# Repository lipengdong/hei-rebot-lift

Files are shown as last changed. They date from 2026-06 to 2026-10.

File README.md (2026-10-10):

<h1 align="center">HEI ReBot Lift</h1>

<p align="center">
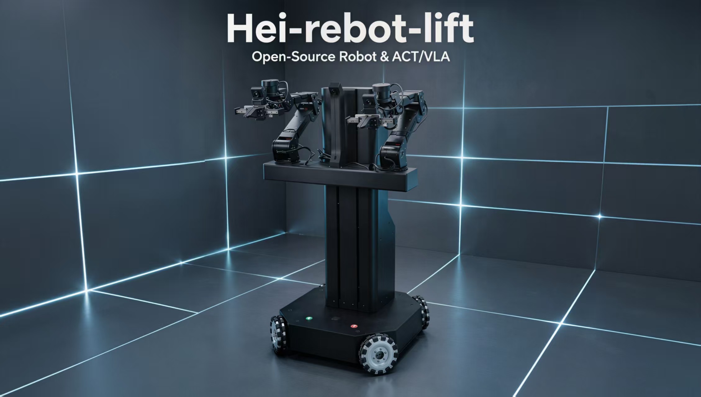
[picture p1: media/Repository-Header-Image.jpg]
HEI ReBot Lift
  
</p>

<p align="center">
  <a href="README.md"><b>English</b></a> <b>|</b>
  <a href="README_zh.md"><b>中文</b></a> <b>|</b>
  <a href="README_Fr.md"><b>français</b></a> <b>|</b>
  <a href="README_es.md"><b>Español</b></a>
</p>

<p align="center">
  <a href="https://github.com/lipengdong/hei-rebot-lift/tree/v0.2.0">
    
  </a>
  <a href="https://github.com/lipengdong/hei-rebot-lift/stargazers">
    
  </a>
</p>

## 🚀 Overview

**HEI ReBot Lift** is a **dual-arm lifting mobile robot project for embodied AI learning, reproduction, and real-robot validation**. Its goal is to **lower the barrier to building real robot learning systems**. It follows the idea of **truly reproducible open source**: not only releasing code, but also organizing **hardware materials, wiring, deployment steps, the VR teleoperation pipeline, dataset recording, ACT/VLA training, and real-robot rollout workflows**, so builders can move from hardware assembly all the way to policy deployment. The robot consists of dual arms, a lift platform, a four-wheel O-type omnidirectional chassis, and three cameras. The software is built on LeRobot and covers MuJoCo/Pinocchio inverse kinematics, LeRobotDataset, imitation learning, and VLA policy deployment.

<p align="center">
  <b>🚀 Dual-Arm Mobile Manipulation</b> · <b>📖 Open Hardware + Software Stack</b> · <b>🤖 LeRobot Ready</b>
</p>

<p align="center">
  <a href="#-quick-setup">🚀 Quick Setup</a> ·
  <a href="#-hardware">🦾 Hardware</a> ·
  <a href="#-startup-flow">🎮 Simulation / Teleoperation</a> ·
  <a href="#-record-data">📷 Record Data</a> ·
  <a href="#-train-act">🧠 Train ACT</a> ·
  <a href="#-train-smolvla">✨ Train VLA</a>
</p>

## ✨ Features

<div align="center">

<table>
  <thead>
    <tr>
      <th align="center">Icon</th>
      <th align="center">Capability</th>
      <th align="center">Description</th>
    </tr>
  </thead>
  <tbody>
    <tr><td align="center">🦾</td><td align="center">Dual-arm manipulation</td><td align="center">Damiao dual arms and grippers for teleoperation, recording, and policy rollout</td></tr>
    <tr><td align="center">⬆️</td><td align="center">Lift platform</td><td align="center">Automatic homing on startup, with the upper limit defined as <code>height.pos = 0</code></td></tr>
    <tr><td align="center">⭕</td><td align="center">Omnidirectional base</td><td align="center">Four-wheel O-type omnidirectional chassis with <code>x/y/theta</code> velocity control</td></tr>
    <tr><td align="center">🎮</td><td align="center">Keyboard / VR control</td><td align="center">Control the complete MuJoCo robot by keyboard or VR; Telegrip + Pinocchio/CasADi provide the VR IK pipeline</td></tr>
    <tr><td align="center">📷</td><td align="center">Three-camera data</td><td align="center"><code>front</code>, <code>left_wrist</code>, and <code>right_wrist</code> visual inputs</td></tr>
    <tr><td align="center">🧠</td><td align="center">Imitation learning / VLA</td><td align="center">Record keyboard/VR simulation data, visualize LeRobotDataset episodes, train ACT/VLA policies, and run them in simulation or on hardware</td></tr>
  </tbody>
</table>

HEI ReBot Lift demo

</div>

## 🤝 Get Your Own Robot / Join the Community

If you want to reproduce your own **HEI ReBot Lift**, you can follow the hardware materials, BOM, wiring notes, and software deployment documents gradually organized in this project to source parts and build the robot yourself. We also welcome builders and researchers interested in dual-arm mobile manipulation, VR teleoperation, LeRobot data collection, ACT/VLA training, and real-robot deployment to exchange ideas with us.

If you want to **get your own robot faster**, or would like to collaborate on hardware reproduction, teaching labs, data collection, algorithm validation, or application deployment, feel free to contact us.

<p align="center">
  <b>WeChat community / collaboration:</b> <code>hgm159951</code> &nbsp;&nbsp;|&nbsp;&nbsp;
  <b>Email:</b> <a href="mailto:hgm159951@163.com">hgm159951@163.com</a>
</p>

Reproductions, discussions, issues, improvements, and real-robot test feedback are all welcome.

## 📁 Project Layout

```text
hei-rebot-lift/
├── README.md
├── README_zh.md
├── README_Fr.md
├── README_es.md
├── LICENSE
├── community/                    # Community notes and collaboration records
├── hardware/                     # Hardware BOM, wiring, device binding, mechanical materials
├── media/                        # Images, videos, and README assets
├── docs/                         # Deployment and usage documentation
└── software/
    └── lerobot-hei-rebot-lift/   # Runnable LeRobot-based software project
```

The runnable software lives in:

```text
software/lerobot-hei-rebot-lift/
```

Quick Setup starts at the repository root. For later sections, open a new
terminal at the repository root for each command block; each block includes its
own `cd`. Replace `192.168.31.127` with your robot IP. The headset connects to
the **computer IP**, not the robot IP. The software directory is:

```bash
cd software/lerobot-hei-rebot-lift
```

## 🖼️ Showcase

<p align="center">
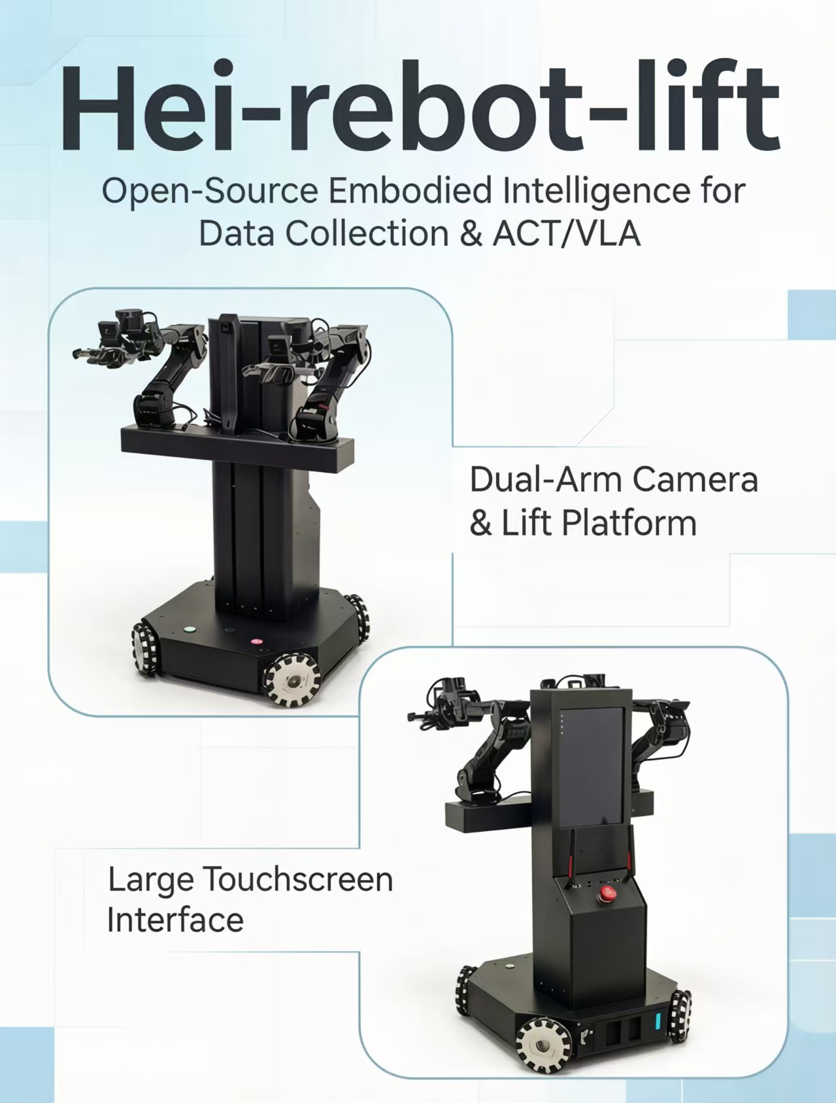
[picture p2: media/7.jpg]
HEI ReBot Lift robot
  
</p>

## ⭐ Star History

<p align="center">
  <a href="https://www.star-history.com/?repos=lipengdong%2Fhei-rebot-lift&type=date&legend=top-left">
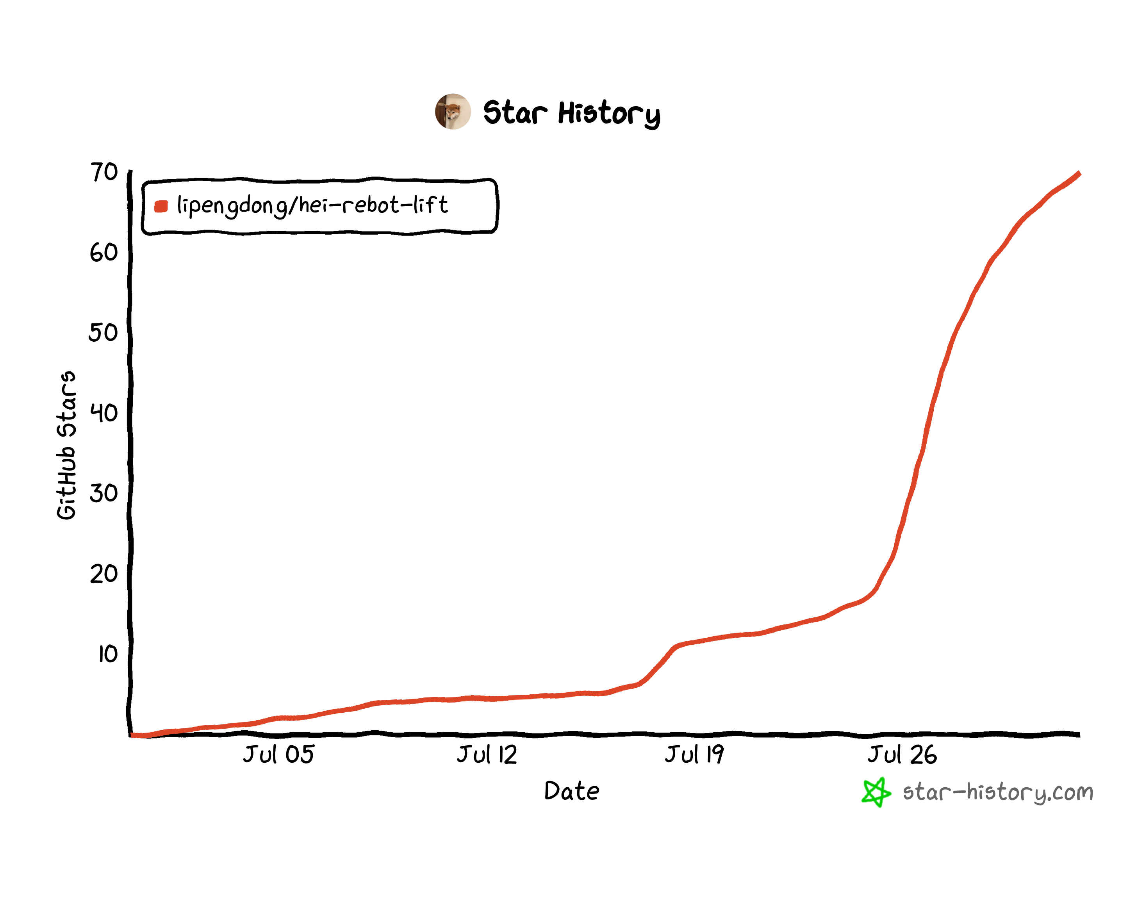
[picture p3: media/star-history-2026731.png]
HEI ReBot Lift Star History
    
  </a>
</p>

## 🗺️ Roadmap & Latest Status

We will continue improving HEI ReBot Lift across hardware materials, software interfaces, data collection workflows, and mainstream embodied AI policy integrations. The table below summarizes the current status and links to the related documentation.

| Module | Status | Current Progress | Related DOC |
| --- | --- | --- | --- |
| Robot body | ✅ First version completed | Dual arms, lift platform, and four-wheel O-type omnidirectional base are integrated and tested as a complete system | [Hardware](hardware/README.md) |
| Complete robot URDF | ✅ Completed | Full robot model includes the chassis, wheels, lift, dual arms, parallel grippers, and TCP frames for simulation and real-robot IK | [URDF Model](software/lerobot-hei-rebot-lift/examples/hei_rebot_lift/VR_mujoco_ik/mujoco_ik/model/HEI_robot_urdf/) |
| MuJoCo simulation testing | ✅ Completed | Keyboard and VR control of both arms, grippers, lift, and chassis have been tested; includes wheel animations, workspace projection, stable demonstrations, and independent contact-physics grasp validation | [Simulation Guide](software/lerobot-hei-rebot-lift/examples/hei_rebot_lift/VR_mujoco_ik/README.md) |
| Simulation data and policy loop | ✅ Verified | Keyboard or VR demonstrations publish synchronized 18-D states/actions and three camera views for LeRobotDataset recording, visualization, ACT training, and MuJoCo policy rollout | [Dataset, Training & Inference Guide](software/lerobot-hei-rebot-lift/examples/hei_rebot_lift/VR_mujoco_ik/mujoco_ik/SIM_DATASET_WORKFLOW.md) |
| Damiao motor driver | ✅ First version completed | `damiao_u2can` is implemented for dual arms, grippers, chassis, and lift motor control | [Damiao U2CAN](software/lerobot-hei-rebot-lift/src/lerobot/motors/damiao_u2can/) |
| Lift platform | ✅ First version completed | Supports upper-limit homing on startup and `height.pos` position-target control | [Robot Driver](software/lerobot-hei-rebot-lift/src/lerobot/robots/hei_rebot_lift/README.md) · [Independent Lift Control](software/lerobot-hei-rebot-lift/examples/hei_rebot_lift/README.md#independent-lift-test) |
| Omnidirectional base | ✅ First version completed | Supports `x.vel`, `y.vel`, and `theta.vel` commands with basic acceleration smoothing | [Robot Driver](software/lerobot-hei-rebot-lift/src/lerobot/robots/hei_rebot_lift/README.md) · [Independent Chassis Control](software/lerobot-hei-rebot-lift/examples/hei_rebot_lift/README.md#independent-chassis-test) |
| Three-camera vision | ✅ First version completed | Supports `front`, `left_wrist`, and `right_wrist` OpenCV cameras with MJPG by default | [Robot Driver](software/lerobot-hei-rebot-lift/src/lerobot/robots/hei_rebot_lift/README.md) |
| VR + MuJoCo IK | ✅ First version completed | Telegrip + MuJoCo + Pinocchio/CasADi is connected to the real-robot control pipeline | [VR MuJoCo IK](software/lerobot-hei-rebot-lift/examples/hei_rebot_lift/VR_mujoco_ik/README.md) |
| LeRobot 0.6.2 integration | ✅ Updated | `hei_rebot_lift` robot/client/host is adapted to the latest upstream interfaces, with teleoperate, record, replay, evaluate, and rollout scripts | [Examples](software/lerobot-hei-rebot-lift/examples/hei_rebot_lift/README.md) |
| Real-robot data collection | ✅ First version completed | Supports LeRobotDataset recording, resume recording, visualization, and bad-episode cleanup | [Record Guide](software/lerobot-hei-rebot-lift/examples/hei_rebot_lift/README.md) |
| ACT training and rollout | ✅ Verified | Supports ACT training and real-robot rollout | [Examples](software/lerobot-hei-rebot-lift/examples/hei_rebot_lift/README.md) |
| SmolVLA / VLA | ✅ Initial support | Supports SmolVLA training and real-robot rollout entry points | [Examples](software/lerobot-hei-rebot-lift/examples/hei_rebot_lift/README.md) |
| Open hardware materials | ✅ Completed | Overall BOM, full robot STEP assembly, printed-part STL files, metal parts list, and STEP/DWG manufacturing files are available | [Hardware](hardware/README.md) |
| Community and reproduction | 🚧 Ongoing | WeChat group, email contact, and GitHub project entry are available | [Community](community/README.md) |
| Other mainstream VLA deployment reproduction | ⏳ Coming soon | Plan to reproduce and test more mainstream VLA policies for training, inference, and real-robot deployment on HEI ReBot Lift | Not completed |

## 🦾 Hardware

The hardware package now includes the overall BOM, full robot STEP assembly, 3D printed parts, and metal/CNC/sheet-metal manufacturing files.

| Resource | File / Directory | Description |
| --- | --- | --- |
| Hardware guide | [hardware/README.md](hardware/README.md) | Hardware directory index, reproduction order, and safety checklist |
| Overall BOM V1.1 | [hardware/HEI_ReBot_Lift_BOM.md](hardware/HEI_ReBot_Lift_BOM.md) / [xlsx](hardware/HEI_ReBot_Lift_BOM.xlsx) | Main purchasing and preparation checklist; verify current prices before purchase |
| Full robot assembly | [hardware/Hei_robot_lift.STEP](hardware/Hei_robot_lift.STEP) | Full STEP model for structure review and assembly reference |
| 3D printed parts | [hardware/3D_Printed_Parts/](hardware/3D_Printed_Parts/) | STL files for printed covers, brackets, lift, chassis, and camera-related parts |
| Metal body parts list | [hardware/Metal_Parts/HEI_Metal_Body_Parts_List.xlsx](hardware/Metal_Parts/HEI_Metal_Body_Parts_List.xlsx) | Metal/CNC/sheet-metal part list |
| Metal CAD files | [hardware/Metal_Parts/step/](hardware/Metal_Parts/step/) / [hardware/Metal_Parts/dwg/](hardware/Metal_Parts/dwg/) | STEP and DWG files for machining communication |

### Assembly and Debugging Tutorial

Scan the QR code for the HEI ReBot Lift assembly and debugging tutorial. Use it
together with the repository BOM, latest CAD files, and safety checklist.

<p align="center">
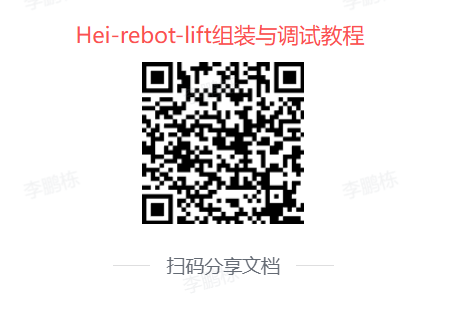
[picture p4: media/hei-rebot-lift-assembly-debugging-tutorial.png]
HEI ReBot Lift assembly and debugging tutorial QR code
  
  <br>
  <em>Scan to open the assembly and debugging tutorial.</em>
</p>

```text
Dual arms: left and right arms with 7 Damiao motors each. Joints 1-3 use DM4340P, joints 4-6 and gripper use DM4310
Chassis: four-wheel O-type omnidirectional mobile base, using DM4310 wheel motors
Lift: lead-screw lift platform using a DM4310 motor. On startup, the upper limit is homed as height.pos = 0
Cameras: three OpenCV cameras: front, left_wrist, right_wrist
Communication: ZMQ between robot-side host and computer-side client
Teleoperation: VR headset and controllers. Telegrip captures VR data; MuJoCo + Pinocchio/CasADi compute IK
```

## 🧩 Software Modules

```text
software/lerobot-hei-rebot-lift/src/lerobot/robots/hei_rebot_lift/        Robot driver
software/lerobot-hei-rebot-lift/src/lerobot/motors/damiao_u2can/          Damiao U2CAN communication
software/lerobot-hei-rebot-lift/examples/hei_rebot_lift/                  Record, replay, evaluate, and rollout scripts
software/lerobot-hei-rebot-lift/examples/hei_rebot_lift/VR_mujoco_ik/     VR + MuJoCo + Pinocchio IK
```

## ⚡ Quick Setup

Both machines need this project's code, but their dependencies and roles differ.
**Start each subsection at the repository root on the specified machine. Do not
execute robot-side and computer-side steps consecutively on one machine.**

| Machine | Environment | Purpose |
| --- | --- | --- |
| Robot-side Jetson | `lerobot5` | Hardware drivers, serial binding, robot host; no VR/IK environment needed |
| Your computer: control/training | `lerobot5` | Teleoperation client, dataset recording/editing, visualization, training, policy inference |
| Your computer: VR/simulation | `hei-rebot-vr` | Telegrip, MuJoCo, Pinocchio/CasADi FK/IK |

### 1. Robot-Side Jetson Installation

**Run only on the robot.** Install the hardware extras without the computer-side
dataset visualization and training extras. This still includes the project's
base dependencies; it is not a standalone driver package without PyTorch.

```bash
cd software/lerobot-hei-rebot-lift
conda create -n lerobot5 python=3.12 -y
conda activate lerobot5
python -m pip install -e ".[hardware,hei_rebot_lift]"
python -c "import serial, zmq, cv2; print('robot dependencies ok')"
```

If a working `lerobot5` environment already exists, skip creation and activate
it before installation. For Jetson PyTorch/torchvision platform or version
conflicts, account for the installed JetPack and this project's version
constraints. Do not copy desktop CUDA wheels or bypass all dependencies with
`--no-deps`.

Next, follow Device Mapping below, verify limit switches and cameras, then start
`hei-rebot-lift-host` using Startup Flow. Do not create `hei-rebot-vr` on the robot.

### 2. Your Computer: Control, Recording, and Training

**Run only on your computer.** This environment runs `teleoperate.py`,
`record.py`, training, replay, and policy inference; it does not directly open
the robot's motor serial ports.

```bash
cd software/lerobot-hei-rebot-lift
conda create -n lerobot5 python=3.12 -y
conda activate lerobot5
python -m pip install -e ".[core_scripts,training,hei_rebot_lift]"
python -m pip show pyzmq rerun-sdk pynput datasets accelerate
```

This includes dataset recording/editing, Rerun visualization, keyboard input,
ZMQ, and general training dependencies. Install SmolVLA-specific dependencies
in its training section below. Skip creation if `lerobot5` already exists.

### 3. Your Computer: VR/MuJoCo IK

On your computer, **open another terminal at the repository root**. Telegrip and
MuJoCo IK share `hei-rebot-vr`; do not mix these dependencies into `lerobot5`.
Use the conda-forge versions in `environment.yml` for FK/IK; do not separately
install `pin` with pip.

```bash
cd software/lerobot-hei-rebot-lift/examples/hei_rebot_lift/VR_mujoco_ik
conda env create -f environment.yml
conda activate hei-rebot-vr
env -u LD_LIBRARY_PATH python -c "import pinocchio as pin; from pinocchio import casadi as cpin; print(pin.__version__); print('casadi binding ok')"
```

For an existing environment, replace creation with
`conda env update -n hei-rebot-vr -f environment.yml --prune`. Launch wrappers
activate it automatically. Test pure simulation before connecting real hardware;
see the [VR deployment guide](software/lerobot-hei-rebot-lift/examples/hei_rebot_lift/VR_mujoco_ik/README.md).

## 🔌 Device Mapping

Stable udev device names are used by default:

```text
/dev/hei_right_arm   Right arm U2CAN
/dev/hei_left_arm    Left arm U2CAN
/dev/hei_chassis     Chassis U2CAN
/dev/hei_lift        Lift motor U2CAN
/dev/hei_lift_io     Lift limit-switch serial port
```

### 1. Serial and Camera Discovery and Binding Wizard

Run [Port_Binding_Wizard.py](software/lerobot-hei-rebot-lift/examples/hei_rebot_lift/debug/Port_Binding_Wizard.py)
on the **robot-side Jetson**. It scans `ttyACM*`, `ttyUSB*`, and `ttyCH341USB*`,
identifies serial adapters from responding motor IDs and limit-switch IO frames, then previews each camera so the user can assign
front, left-wrist, right-wrist, or skip it. Missing cameras do not stop available
devices from being bound. It does not enable motors, write zeros, or command motion.

**Prepare the hardware:**

1. Stop `hei-rebot-lift-host` and all motor/serial debug programs so the ports are free.
2. Power down and support the arms before changing wiring. Temporarily disconnect **right-arm IDs 4-7**, leaving IDs 1-3 connected; keep the left arm fully connected on IDs 1-7.
3. Check chassis IDs 1-4, lift ID 1, and the lift limit-switch IO wiring. Power the four U2CAN boards, IO board, and motors needed for discovery.
4. Keep USB sockets unchanged throughout scanning and rule installation.

Set serial-port read/write permissions before running the Python wizard:

```bash
sudo chmod 666 /dev/ttyACM*
sudo chmod 666 /dev/ttyUSB*
sudo chmod 666 /dev/ttyCH341USB*
```

Start the interactive wizard from the repository root:

```bash
cd software/lerobot-hei-rebot-lift
PYTHONPATH=src conda run --no-capture-output -n lerobot5 \
  python -u examples/hei_rebot_lift/debug/Port_Binding_Wizard.py
```

Review the scan, confirm the arm/chassis/lift/IO mapping, and choose whether to
install the system rules. The default output is
`examples/hei_rebot_lift/rules/99-nx-robot.rules`, with an existing-file backup.
Installation into `/etc/udev/rules.d/` requires `sudo`; the wizard reloads rules
and checks symlinks. Existing lidar and IMU rules are preserved; those devices
are not identified by this scan.

**Verify the bindings:**

```bash
ls -l /dev/hei_right_arm /dev/hei_left_arm /dev/hei_chassis /dev/hei_lift /dev/hei_lift_io
ls -l /dev/hei_front_camera /dev/hei_left_wrist_camera /dev/hei_right_wrist_camera
```

If a symlink is missing, reconnect that USB device to the same socket and check
again. After verification, power down, reconnect right-arm IDs 4-7, and power up
before independent hardware tests below. Rules follow physical USB topology: keep each adapter
in its original socket, and rebind after changing sockets or hubs.

For missing/ambiguous devices, busy ports, or invalid IO frames, check power,
USB/CAN wiring, motor IDs, competing processes, and the IO baud rate before
accepting any mapping. For permission errors, check serial access (usually the
`dialout` group). Use interactive mode for first deployment. `--yes --install`
skips camera preview and preserves existing camera rules; use `--skip-cameras`
when rebinding serial devices only.

### 2. After Binding: Arm Zeros and Independent Hardware Tests

**Run all tests on the robot-side Jetson; no VR or computer client is needed.**
Run one debug tool at a time with the host and other serial programs stopped.
Each block starts in a new terminal at the repository root. For keyboard tools,
activate `lerobot5` and run Python directly in an interactive terminal; allocate
a TTY for SSH (for example, `ssh -t USER@ROBOT_IP`). Dashboards refresh in place.
Keep the physical emergency stop reachable; software stop keys do not replace it.

#### 2.1 Position the Arm at Its Designed Mechanical Zero Before Writing

**Warning: `Arm_Zero_Status_Test.py` immediately disables and writes zeros to
all seven motors (IDs 1-7) on that arm. It has no confirmation or read-only mode.
Do not start it at an arbitrary pose or use it for routine status inspection.**
Support the arms before disabling motors, as they can fall under gravity.

Use the assembly design and joint-zero definitions in the
[complete URDF model](software/lerobot-hei-rebot-lift/examples/hei_rebot_lift/VR_mujoco_ik/mujoco_ik/model/HEI_robot_urdf/)
to position the arm at its mechanical zero, not the VR controller's default
working pose. The physical gripper zero is closed (`0 rad`); do not force it
against its stop. The script cannot verify the pose. If the designed zero is
unclear, check the assembly references before writing anything.

<p align="center">
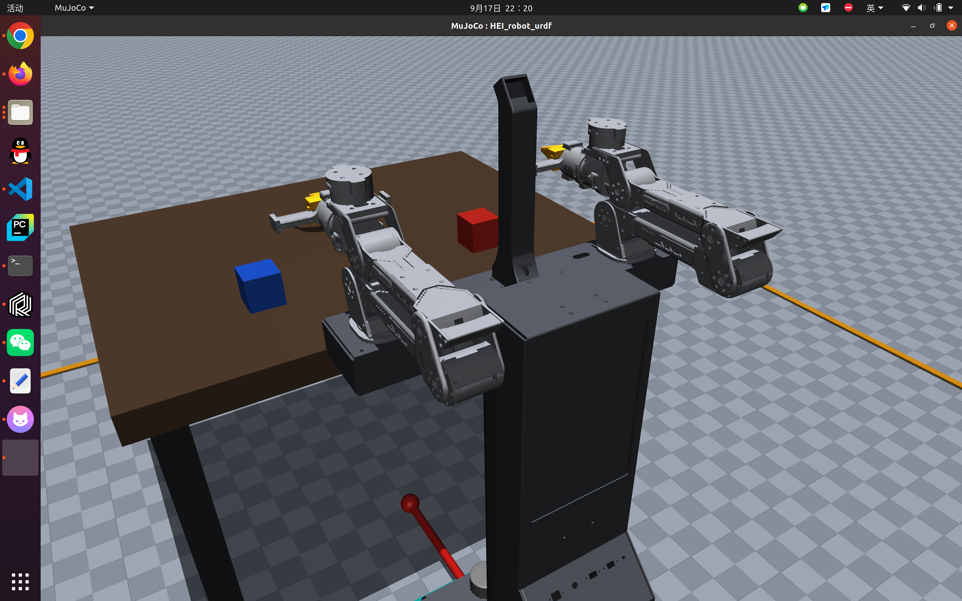
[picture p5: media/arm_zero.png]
Designed mechanical zero posture of both arms
  
  <br>
  <em>Designed mechanical zero posture reference. Verify each joint against the assembly design before writing zeros; this is not the VR working pose.</em>
</p>

Write the right-arm zeros:

```bash
cd software/lerobot-hei-rebot-lift
conda activate lerobot5
PYTHONPATH=src python -u examples/hei_rebot_lift/debug/Arm_Zero_Status_Test.py \
  --port /dev/hei_right_arm
```

Exit with `Ctrl+C`, correctly position the left arm, and then run:

```bash
cd software/lerobot-hei-rebot-lift
conda activate lerobot5
PYTHONPATH=src python -u examples/hei_rebot_lift/debug/Arm_Zero_Status_Test.py \
  --port /dev/hei_left_arm
```

The script keeps motors disabled after writing and refreshes
`POS/VEL/TORQUE/ERROR`. Verify all seven motors are connected and responding
before checking positions near zero. A displayed zero alone does not establish
connectivity or successful calibration. Interpret `ERROR` according to the motor
protocol; not every nonzero state is a fault. Exit after calibration; rewrite
zeros only when assembly or maintenance requires recalibration.

#### 2.2 Independent Chassis Test: Directions, Gears, and Wheel Feedback

Secure the chassis with wheels off the ground, clear of cables and people.
This tool connects only the chassis, not the arms, lift, or cameras.
**All four wheels move through chassis kinematics; this is not single-wheel jog.**

```bash
cd software/lerobot-hei-rebot-lift
conda activate lerobot5
PYTHONPATH=src python -u examples/hei_rebot_lift/debug/Chassis_Status_Test.py \
  --port /dev/hei_chassis
```

| Key | Function |
| --- | --- |
| `1 / 2 / 3` | Low / medium / high gear; begin with low gear `1` |
| `W / S` | Forward / backward |
| `A / D` | Strafe left / right |
| `Q / E` | Rotate left / right |
| `Space` | Software command for zero speed on all wheels |
| `X` or `Ctrl+C` | Exit and stop the chassis |

Hold or repeat a direction key to maintain motion; the default key watchdog
clears the request after `0.65 s` without another direction event. Test each
direction briefly while observing requested/reconstructed body velocity and
each wheel's target/measured angular velocity, position, torque, and state code.
Body velocities use driver command units, not directly measured meters/second.

| Motor ID | Wheel position | Dashboard label |
| --- | --- | --- |
| `1` | Right front | `RF` |
| `2` | Right rear | `RR` |
| `3` | Left rear | `LR` |
| `4` | Left front | `LF` |

Stop for a stationary wheel, incorrect mapping, missing feedback, or abnormal
shaking; check IDs, wiring, and configuration rather than increasing speed.
After the suspended test passes, verify physical directions at low gear in a
clear area. Single-wheel jogging needs a separate mode not provided by this
tool; never substitute the arm zero-writing script on the chassis port.

#### 2.3 Independent Lift Test: Homing, Height, and Limit IO

**Startup automatically homes upward.** Check both limit-switch connections and
clear the travel path first. Support structures that could fall when disabled
and keep the emergency stop ready. This tool reuses production lift logic and
opens only the lift motor and limit IO ports.

```bash
cd software/lerobot-hei-rebot-lift
conda activate lerobot5
PYTHONPATH=src python -u examples/hei_rebot_lift/debug/Lift_Status_Test.py \
  --motor-port /dev/hei_lift --io-port /dev/hei_lift_io --height-step-mm 2
```

| Key | Function |
| --- | --- |
| `I / K` | Raise / lower target height; this example changes it by `2 mm` per key event |
| `Space` | Stop and use current reported height as the hold target |
| `H` | Home upward again, only with a safe travel path |
| `X` or `Ctrl+C` | Exit, stop, and disable |

Upper-limit homing defines `0 mm`; downward heights are negative, within
`-700..0 mm`. Move down and up in small steps while checking current/target
height, error, measured speed, motor command speed, IO freshness, and limits.
Confirm the relevant IO state at a known limit. Stop for offline IO, both limits
active, or incorrect states; investigate before retrying rather than repeatedly
driving into end stops.

**Finish all independent tests and exit the debug tools** before the simulation
practice and real startup below. Never let a debug tool compete with the host
for a serial port.

### 3. Camera Mapping

Default cameras (verify actual devices on the **robot**, not your computer):

```text
front       /dev/hei_front_camera
left_wrist  /dev/hei_left_wrist_camera
right_wrist /dev/hei_right_wrist_camera
```

Find connected cameras:

```bash
cd software/lerobot-hei-rebot-lift
PYTHONPATH=src conda run --no-capture-output -n lerobot5 \
  lerobot-find-cameras opencv --opencv-fourcc MJPG --opencv-width 640 --opencv-height 480 --opencv-fps 30
```

### Stable Camera Mapping

The binding wizard above creates stable `/dev/hei_*_camera` symlinks, so camera
IDs normally require no further edits. Run the wizard again after moving a
camera to another physical USB socket.

To manually override a camera device ID or path, edit
`software/lerobot-hei-rebot-lift/src/lerobot/robots/hei_rebot_lift/config_hei_rebot_lift.py`,
then change the corresponding `index_or_path` in `hei_rebot_lift_cameras_config()`:

```python
def hei_rebot_lift_cameras_config() -> dict[str, CameraConfig]:
    return {
        "front": OpenCVCameraConfig(index_or_path="/dev/hei_front_camera", fps=30, width=640, height=480, fourcc="MJPG"),
        "left_wrist": OpenCVCameraConfig(index_or_path="/dev/hei_left_wrist_camera", fps=30, width=640, height=480, fourcc="MJPG"),
        "right_wrist": OpenCVCameraConfig(index_or_path="/dev/hei_right_wrist_camera", fps=30, width=640, height=480, fourcc="MJPG"),
    }
```

Keep the names `front`, `left_wrist`, and `right_wrist` unchanged: datasets,
policies, and clients use these keys. Do not edit `camera_opencv.py` or the VR
YAML for USB IDs. A separate client keeps the same camera keys and dimensions;
the robot host opens the physical USB devices.

## 🎮 Startup Flow

### Identify the Computer and Robot IPs First

The examples use your computer IP `192.168.31.245` and example robot IP
`192.168.31.127`. **If the robot address differs, replace robot addresses only;
do not replace the computer address used by the headset.**

| Address | Owner | Used for |
| --- | --- | --- |
| `192.168.31.245` | Your control computer running Telegrip and MuJoCo IK | Headset browser: `https://192.168.31.245:8443` |
| `192.168.31.127` | Robot Jetson running the host | Client: `--remote-ip 192.168.31.127`; VR camera endpoint: `tcp://192.168.31.127:6556` |
| `localhost` / `127.0.0.1` | The machine running that program, not the remote robot | Local VR, action, and feedback connections when Telegrip, MuJoCo IK, and the client share one computer |

Practice in pure simulation below before real control. Keyboard simulation only
needs the computer; VR simulation needs the computer and headset to communicate. For real control, also connect the
robot to the same mutually reachable LAN. **Run each block in a new terminal at
the repository root on the specified machine.** Keep long-running processes open.

### 1. Beginner Practice: Computer-Side Pure Simulation (No Hardware)

<p align="center">
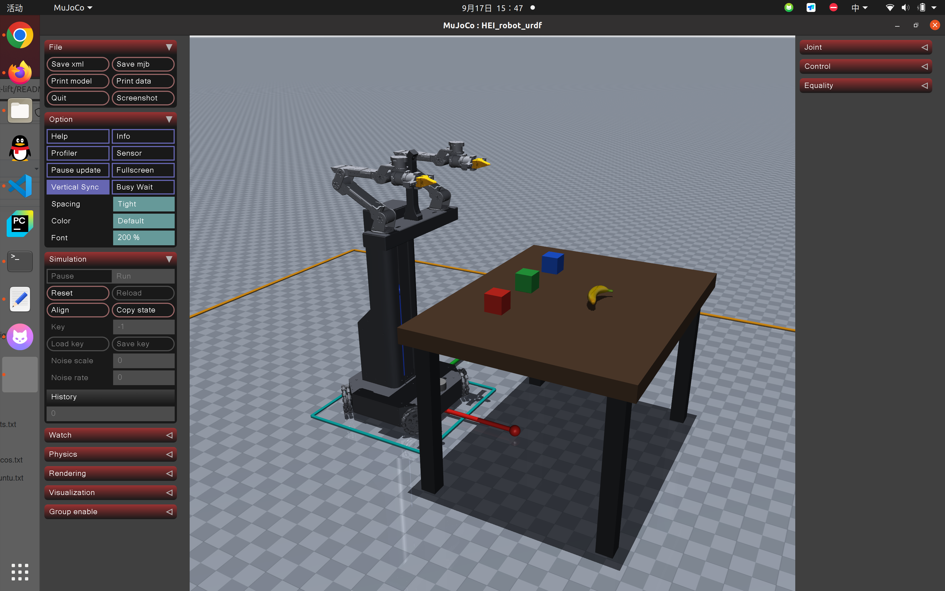
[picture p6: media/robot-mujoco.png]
HEI ReBot Lift VR simulation in MuJoCo
  
</p>

Install `hei-rebot-vr` first. **Do not start the robot host, `teleoperate.py`,
`record.py`, or the real bridge during practice; stop them if already running.**
Pure simulation requires no motors, device bindings, or robot feedback and does
not publish real actions on `6558`.

#### 1.1 Practice by Keyboard Without a Headset

```bash
cd software/lerobot-hei-rebot-lift/examples/hei_rebot_lift/VR_mujoco_ik
./run_hei_robot_keyboard_sim.sh
```

Press `1/2/3/4` to select chassis, lift, left arm, or right arm. Chassis uses
`W/S`, `A/D`, and `Q/E`; lift uses `I/K`; arm TCP translation uses `W/S`,
`A/D`, and `R/F`, while rotation uses `U/J`, `I/K`, and `O/L`. Use `Z/X` to
open/close the selected gripper, and `5/6` to reset the left/right arm gradually. See the
[keyboard and VR simulation guide](software/lerobot-hei-rebot-lift/examples/hei_rebot_lift/VR_mujoco_ik/README.md)
for all controls and speed options.

#### 1.2 Computer VR Practice Terminal A: Start Telegrip

```bash
cd software/lerobot-hei-rebot-lift/examples/hei_rebot_lift/VR_mujoco_ik
./run_telegrip.sh
```

Connect the headset and computer to the same LAN. In the headset browser, open
`https://192.168.31.245:8443` (computer IP), verify the self-signed certificate
warning, and enter VR.

#### 1.3 Computer VR Practice Terminal B: Start the Complete Robot Simulation

```bash
cd software/lerobot-hei-rebot-lift/examples/hei_rebot_lift/VR_mujoco_ik
./run_hei_robot_vr_sim.sh
```

Observe the robot in the **MuJoCo window on your computer**. The scene includes
both arms, parallel grippers, lift, four-wheel omnidirectional chassis, a table,
cubes, and a banana for pick-and-place practice. Without a physical robot, no
real camera feed will appear in the headset; simulation still works.
`vr_images.enabled` is currently `false` in `telegrip/config.yaml`; leave it
disabled for practice. Changing it requires restarting Telegrip.

#### 1.4 Practice Controller Inputs in Order

<table align="center">
  <tr>
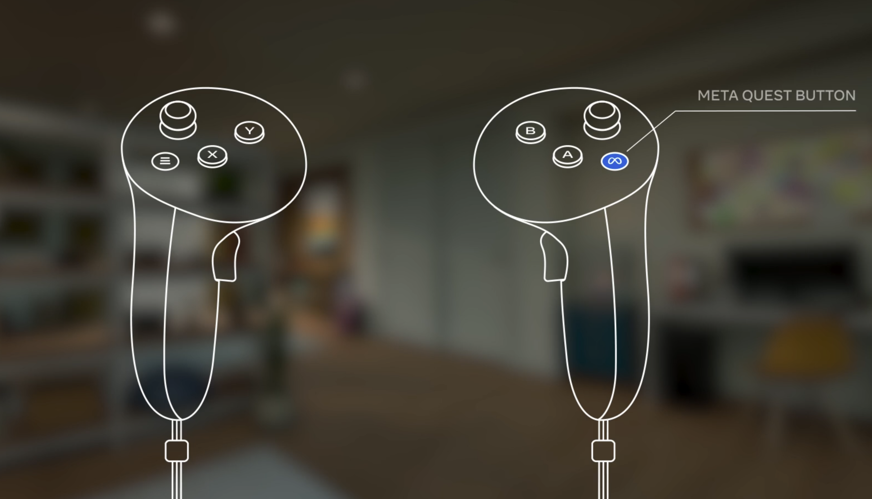
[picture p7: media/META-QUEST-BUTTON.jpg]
Meta Quest system button on the right controller
    <td align="center"><br><b>Meta Quest System Button</b></td>
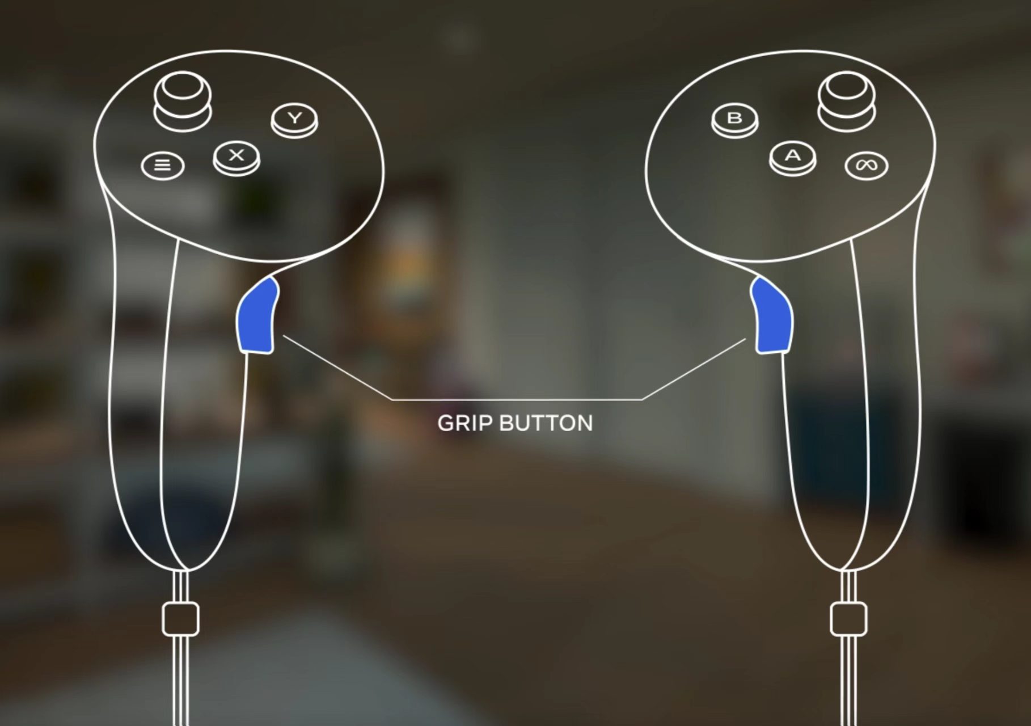
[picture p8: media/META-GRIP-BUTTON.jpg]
Side grip button location
    <td align="center"><br><b>Grip: Side Button</b></td>
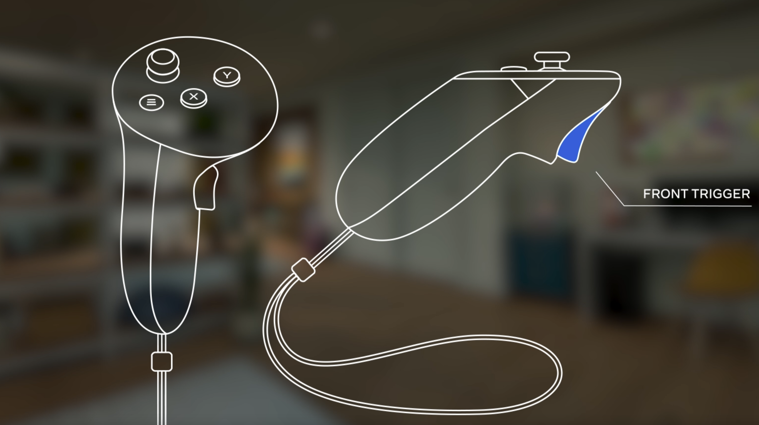
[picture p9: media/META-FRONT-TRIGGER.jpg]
Front trigger location
    <td align="center"><br><b>Trigger: Front Trigger</b></td>
  </tr>
</table>

Click an image to view it at full size.

> [!IMPORTANT]
> **Calibrate the VR origin before control: hold the right controller's META QUEST BUTTON for about 3 seconds to recenter using the headset's current position and heading as the VR reference origin for this session.**
> **Recalibrate after changing your standing/seated position or operating direction. If controller motion and arm motion point in different directions or directional tracking feels wrong, stop control and recalibrate before continuing.**
> Sequence: **release both `grip` buttons → center the sticks → face the intended forward direction from your new position → hold the Meta Quest button for about 3 seconds → let tracking settle and hold `grip` again**. Verify direction with a small movement first.

The Meta Quest button recenters the **headset/VR reference frame**; `grip`
captures each arm's relative control origin. These are different operations.
Neither writes motor zeros nor replaces lift homing. Follow the calibration
procedure for both simulated and real VR control.

| Exercise | Procedure |
| --- | --- |
| Single-arm translation and rotation | Hold that side's `grip` to capture a relative origin; make small XYZ translations and rotations while observing the TCP. Practice each arm separately |
| Release and recapture the origin | Release `grip` to stop tracking, reposition the controller comfortably, then hold it again; the arm need not follow the controller back to its origin |
| Gripper pick and place | Simulation grippers start closed; real startup restores measured state. While holding `grip`, press `trigger` to open and release it to close; close near an object for stable-grasp practice, then open to place it |
| Lift | Left `grip` + left stick vertical; releasing left `grip` stops the lift request |
| Chassis | Right `grip` + right stick for forward/backward and strafing; right `B` rotates clockwise, left `Y` counterclockwise; releasing right `grip` stops the request |
| Recording shortcuts | Release both `grip` buttons; right `B` emulates Right Arrow to finish/save the episode, and left `Y` emulates Left Arrow to discard/re-record it |
| Reset | With the corresponding `grip` released, right `A` / left `X` gradually resets that arm. Focus the computer's MuJoCo window and press `R` to reset the robot and objects, in pure simulation only |

Keep sticks centered when practicing arm motion to avoid unintended chassis or
lift movement. At joint/workspace boundaries, reduce motion and return to the
reachable area instead of pushing farther out. See the
[controller tutorial](software/lerobot-hei-rebot-lift/examples/hei_rebot_lift/VR_mujoco_ik/README.md)
for complete instructions.

#### 1.5 Validate Contact-Physics Grasping (Optional)

The ordinary keyboard/VR simulators use stable TCP attachment for repeatable
practice and data collection. To test free-body collision, gravity, bilateral
finger contact, slip, and release instead, start one of the independent physics
modes:

```bash
cd software/lerobot-hei-rebot-lift/examples/hei_rebot_lift/VR_mujoco_ik
./run_hei_robot_keyboard_physics.sh
# Or, after starting Telegrip:
./run_hei_robot_vr_physics.sh
```

The physics scene uses `50 mm` cubes, flat high-friction finger pads, `5 mm`
contact preload, and a force-limited tangential assist capped at `6 N`. Objects
remain free MuJoCo bodies: opening the gripper removes the assist immediately
and the object falls normally. See the
[Physical Grasp Simulation Guide](software/lerobot-hei-rebot-lift/examples/hei_rebot_lift/VR_mujoco_ik/mujoco_ik/PHYSICS_GRASP_SIMULATION.md)
for controls, parameters, and headless validation commands.

#### 1.6 Collect, Train, and Run Policies in Simulation

The complete MuJoCo environment is also a reproducible policy-development
environment. Demonstrations can be controlled by **keyboard or VR**, recorded
with the same 18-D state/action schema and `front`, `left_wrist`, and
`right_wrist` camera keys used by the robot, then visualized, trained, and
played back through a policy in MuJoCo.

| Stage | MuJoCo process (`hei-rebot-vr`) | LeRobot process (`lerobot5`) |
| --- | --- | --- |
| Keyboard demonstration | `run_hei_robot_keyboard_dataset_sim.sh` | `run_hei_robot_keyboard_record.sh` |
| VR demonstration | Telegrip + `run_hei_robot_vr_dataset_sim.sh` | `run_hei_robot_mujoco_record.sh` |
| Dataset inspection | - | `lerobot-dataset-viz` or `inspect_mujoco_dataset.py` |
| Policy training | - | `lerobot-train` with ACT or another supported policy |
| Simulation inference | `run_hei_robot_policy_sim.sh` | `run_hei_robot_mujoco_rollout.sh` |

The ordinary `run_hei_robot_keyboard_sim.sh` and `run_hei_robot_vr_sim.sh`
commands are practice-only and do not publish dataset samples. Recording uses
the dedicated `*_dataset_sim.sh` server plus its recorder in a second terminal.
Keep the simulation and recording FPS equal.

Follow the **[MuJoCo Dataset, Training, and Inference Guide](software/lerobot-hei-rebot-lift/examples/hei_rebot_lift/VR_mujoco_ik/mujoco_ik/SIM_DATASET_WORKFLOW.md)**
for exact environment boundaries, launch commands, keyboard/VR recording,
episode visualization, ACT training, and policy rollout. This workflow never
connects to the physical robot unless you separately start the real-robot
programs.

#### 1.7 Move to Hardware Only After Practice

- Control each arm's translation/rotation and confidently release/recapture the relative origin with `grip`.
- Recenter with the Meta Quest button and know to recalibrate after moving, changing heading, or observing a direction mismatch.
- Complete a pick-and-place exercise and understand that gripper state persists after releasing `grip`.
- Control chassis/lift directions, stop their requests, and keep sticks centered.
- Distinguish simulation and real launch scripts, locate the emergency stop, and understand real workspace hazards.

Close the pure-simulation viewer or stop it with `Ctrl+C`, then follow sections
2 and 3 below. Telegrip may stay running. If camera streaming was disabled,
restore `vr_images.enabled: true`, check the robot camera IP, and restart
Telegrip when real camera display is needed; do not launch duplicate instances.
**Simulation practice does not replace hardware safety checks.** Stable grasping
is a kinematic demonstration; the optional physics mode validates simulated
contact and release but still cannot prove real motor load capacity. Motor
directions, zeros, limits, and load capacity require independent verification,
and simulation lift speed can differ from real hardware.

### 2. Robot-Side Jetson: Start the Host (Terminal 1)

Run only on the robot. Complete device mapping, clear the workspace, and keep
the emergency stop reachable. Startup moves the lift upward to home;
**wait for homing to finish** before proceeding. The host runs on the robot;
it does not need the computer IP and is not the computer-side client.

```bash
cd software/lerobot-hei-rebot-lift
PYTHONPATH=src conda run --no-capture-output -n lerobot5 hei-rebot-lift-host
```

Keep this robot terminal running. Do not start Telegrip or MuJoCo IK on Jetson.

### 3. Your Computer: Start the Control Programs

Run all three programs below on **your computer** at `192.168.31.245`, not on Jetson.

#### 3.1 Start Telegrip (Computer Terminal 2)

```bash
cd software/lerobot-hei-rebot-lift/examples/hei_rebot_lift/VR_mujoco_ik
./run_telegrip.sh
```

#### 3.2 Headset Browser: Open the Computer's Page

For example, if the computer running Telegrip has LAN IP `192.168.31.245`, enter
this address in the **VR headset browser**:

```text
https://192.168.31.245:8443
```

Connect the headset and computer to the same LAN and start `run_telegrip.sh`
before opening the page. Use the **computer IP, not the robot IP**, and use
`https`. On the first visit, verify that the address belongs to your computer
before continuing past the self-signed certificate warning, then enter VR using
the page controls.

VR camera display is currently disabled. To enable it, set
`vr_images.enabled: true` and
`vr_images.endpoint: tcp://192.168.31.127:6556` in the computer's
`software/lerobot-hei-rebot-lift/examples/hei_rebot_lift/VR_mujoco_ik/telegrip/config.yaml`.
This must use the **robot IP**. Restart Telegrip after editing it; the client's
`--remote-ip` does not update this configuration.

#### 3.3 Start the Teleoperation Client (Computer Terminal 3)

Set `--remote-ip` to the **robot Jetson IP**, not the computer's `192.168.31.245`.
The client supplies robot feedback and waits for MuJoCo IK actions:

```bash
cd software/lerobot-hei-rebot-lift
PYTHONPATH=src conda run --no-capture-output -n lerobot5 python -u examples/hei_rebot_lift/teleoperate.py --remote-ip 192.168.31.127
```

#### 3.4 Start the Complete-Model Real Bridge (Computer Terminal 4)

Run on the same computer as Telegrip and the client. Default internal
connections stay local; do not replace their addresses with the robot IP:

```bash
cd software/lerobot-hei-rebot-lift/examples/hei_rebot_lift/VR_mujoco_ik
./run_hei_robot_vr_real.sh --enable-real-publish
```

With fresh robot feedback and VR data, release both grip buttons together and
wait for `command bridge ARMED`. The flag acknowledges real command publishing;
it does not bypass synchronization. For simulation only, use
`./run_hei_robot_vr_sim.sh`; the legacy dual-arm entry is `./run_mujoco_ik.sh`.
See the [VR guide](software/lerobot-hei-rebot-lift/examples/hei_rebot_lift/VR_mujoco_ik/README.md)
for controller inputs, recovery, and lift visualization limitations.

Keep **one robot-side host and three computer-side programs** running. To record
data, replace `teleoperate.py` in computer terminal 3 with `record.py`; never run
both together.

## 📷 Record Data

Stop `teleoperate.py` first. `record.py` replaces it as the action receiver and
feedback publisher; never run both together. Keep the host and Telegrip running,
then release both grips to re-arm the bridge after feedback reconnects.

```bash
cd software/lerobot-hei-rebot-lift
PYTHONPATH=src conda run --no-capture-output -n lerobot5 python -u examples/hei_rebot_lift/record.py   --repo-id HGM/hei_rebot_lift_task1   --remote-ip 192.168.31.127   --num-episodes 5   --episode-time-sec 120   --reset-time-sec 30   --task-description "Pick up the yellow block from the floor and put it on the table in front"
```

By default, data is saved locally and is not pushed to the Hugging Face Hub. Add `--push-to-hub` when uploading is needed.

## 🧠 Train ACT

Train on your computer; no robot host or VR process is required. Use the actual
dataset path printed during recording. If you chose a custom `--root`, also pass
`--dataset.root=YOUR_DATASET_PATH`; the dataset ID must match. These short runs
are smoke tests, not a guarantee of a deployable policy.

```bash
cd software/lerobot-hei-rebot-lift
PYTHONPATH=src conda run --no-capture-output -n lerobot5 lerobot-train   --dataset.repo_id=HGM/hei_rebot_lift_task1   --policy.type=act   --policy.device=cuda   --policy.push_to_hub=false   --output_dir=outputs/train/act_hei_rebot_lift_task1   --job_name=act_hei_rebot_lift_task1   --batch_size=8   --steps=10000   --save_freq=10000   --log_freq=200   --num_workers=4   --wandb.enable=false
```

## ✨ Train SmolVLA

Install the policy-specific dependencies first (new terminal at repository root):

```bash
cd software/lerobot-hei-rebot-lift
conda run --no-capture-output -n lerobot5 python -m pip install -e ".[smolvla]"
```

The general `training` extra does not install every VLA policy's dependencies.

```bash
cd software/lerobot-hei-rebot-lift
PYTHONPATH=src conda run --no-capture-output -n lerobot5 lerobot-train   --dataset.repo_id=HGM/hei_rebot_lift_task1   --policy.type=smolvla   --policy.device=cuda   --policy.push_to_hub=false   --output_dir=outputs/train/smolvla_hei_rebot_lift_task1   --job_name=smolvla_hei_rebot_lift_task1   --batch_size=1   --steps=1000   --save_freq=1000   --log_freq=50   --num_workers=2   --wandb.enable=false
```

## 🤖 Real-Robot Rollout

Keep the robot host running, but stop VR command publishing and any teleoperation,
recording, or replay process first. Use only one robot command source. Confirm the
checkpoint exists and camera names match the training data; start with a clear
workspace and a short test.

ACT rollout:

```bash
cd software/lerobot-hei-rebot-lift
PYTHONPATH=src conda run --no-capture-output -n lerobot5 python -u examples/hei_rebot_lift/rollout.py   --remote-ip 192.168.31.127   --model-id outputs/train/act_hei_rebot_lift_task1/checkpoints/010000/pretrained_model   --task "Pick up the yellow block from the floor and put it on the table in front"   --duration-sec 30   --inference sync
```

SmolVLA rollout:

```bash
cd software/lerobot-hei-rebot-lift
PYTHONPATH=src conda run --no-capture-output -n lerobot5 python -u examples/hei_rebot_lift/rollout.py   --remote-ip 192.168.31.127   --model-id outputs/train/smolvla_hei_rebot_lift_task1/checkpoints/001000/pretrained_model   --task "Pick up the yellow block from the floor and put it on the table in front"   --duration-sec 60   --fps 10   --inference rtc
```

## 📖 More Documentation

- [Documentation index](docs/README.md)
- [Recording, resume, training, and rollout](software/lerobot-hei-rebot-lift/examples/hei_rebot_lift/README.md)
- [Robot configuration, lift units, and watchdog](software/lerobot-hei-rebot-lift/src/lerobot/robots/hei_rebot_lift/README.md)
- [VR deployment, controller tutorial, and self-checks](software/lerobot-hei-rebot-lift/examples/hei_rebot_lift/VR_mujoco_ik/README.md)

## 🙏 References & Acknowledgments

The development of HEI ReBot Lift benefits from several excellent open-source projects and community efforts. In particular, we would like to thank:

- **LeRobot**: for providing a unified robot interface, the LeRobotDataset format, training utilities, and policy implementations such as ACT and SmolVLA, which form a strong foundation for real-robot data collection, training, and deployment.
- **reBot / reBot-DevArm**: for open robotic arm hardware, model resources, and practical references for embodied AI open-source projects. It also inspired the way this project organizes hardware materials, deployment documentation, and reproducible workflows.

This project customizes and extends ideas from these open-source ecosystems, aiming to further lower the barrier to learning, reproducing, collecting data with, and deploying policies on a dual-arm lifting mobile robot.

## 📄 License

This project is built on top of Hugging Face LeRobot and keeps the LeRobot dataset, training, policy, and robot-interface ecosystem. Please also follow the original LeRobot license requirements.

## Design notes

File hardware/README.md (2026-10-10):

# HEI ReBot Lift Hardware

[English](README.md) | [中文](README_zh.md)

This directory contains the hardware release package for **HEI ReBot Lift**, a dual-arm mobile manipulation robot with a lift platform and a four-wheel O-type omnidirectional chassis.

The goal of this hardware folder is to make the robot easier to reproduce: not only software, but also the practical files needed for sourcing, machining, 3D printing, assembly review, and later maintenance.

## Release Updates

### 2026-09-21

The BOM was upgraded to V1.1, the full robot assembly was updated, and the
printed-part release was reorganized. Most repository paths were retained;
the chassis copies listed below use their current names:

| Updated file | Change |
| --- | --- |
| [HEI_ReBot_Lift_BOM.md](HEI_ReBot_Lift_BOM.md) / [xlsx](HEI_ReBot_Lift_BOM.xlsx) | Updated to BOM V1.1; Markdown totals were regenerated from recalculated Excel formulas |
| [Hei_robot_lift.STEP](Hei_robot_lift.STEP) | Replaced with the latest complete robot STEP assembly |
| [part_dianchi_ke_1.STL](3D_Printed_Parts/part_dianchi_ke_1.STL) | Updated battery enclosure part 1 |
| [part_dianchi_ke_2.STL](3D_Printed_Parts/part_dianchi_ke_2.STL) | Updated battery enclosure part 2 |
| [part_dipan_3-1.STL](3D_Printed_Parts/part_dipan_3-1.STL) | Updated chassis printed part 3-1 |
| [part_dipan_3_2.STL](3D_Printed_Parts/part_dipan_3_2.STL) | Current chassis part 3, print copy 2 |
| [part_dipan_3_3.STL](3D_Printed_Parts/part_dipan_3_3.STL) | Current chassis part 3, print copy 3 |
| [part_dipan_3_4.STL](3D_Printed_Parts/part_dipan_3_4.STL) | Current chassis part 3, print copy 4 |

The legacy `part_dipan_3.STL` and hyphen-named `part_dipan_3-2/-3/-4.STL`
files were removed. The three underscore-named files are identical by design
and represent three physical copies to print, not three different geometries.

Re-download these files before machining or printing. Previously printed parts
may not match the latest assembly; verify mating surfaces and holes in the new
STEP model before reusing old parts.

## 📁 Directory Layout

```text
hardware/
├── README.md                         # English hardware guide
├── README_zh.md                      # Chinese hardware guide
├── HEI_ReBot_Lift_BOM.md                        # GitHub-readable BOM table
├── HEI_ReBot_Lift_BOM.xlsx                      # Original editable BOM spreadsheet
├── Hei_robot_lift.STEP               # Full robot STEP assembly
├── 3D_Printed_Parts/                 # STL files for printed parts
└── Metal_Parts/
    ├── HEI_Metal_Body_Parts_List.xlsx       # Metal body parts list
    ├── step/                         # STEP files for metal/CNC/sheet-metal parts
    └── dwg/                          # DWG drawings for manufacturing reference
```

## 🧾 Main Files

| File | Purpose | Notes |
| --- | --- | --- |
| [HEI_ReBot_Lift_BOM.md](HEI_ReBot_Lift_BOM.md) / [xlsx](HEI_ReBot_Lift_BOM.xlsx) | Overall robot BOM V1.1 | Markdown for online viewing, Excel for editing; verify current prices before purchase |
| [Hei_robot_lift.STEP](Hei_robot_lift.STEP) | Full robot assembly model | Use this first to inspect the complete mechanical structure and spatial layout |
| [Metal_Parts/HEI_Metal_Body_Parts_List.xlsx](Metal_Parts/HEI_Metal_Body_Parts_List.xlsx) | Metal body parts list | Used with `Metal_Parts/step/` and `Metal_Parts/dwg/` for machining |
| [3D_Printed_Parts/](3D_Printed_Parts/) | 3D printed parts | STL files for printed covers, brackets, lift and camera-related parts |
| [Metal_Parts/step/](Metal_Parts/step/) | Metal STEP files | 3D CAD files for CNC/sheet-metal communication and assembly check |
| [Metal_Parts/dwg/](Metal_Parts/dwg/) | Metal DWG drawings | 2D drawing files for manufacturing reference |

## Assembly and Debugging Tutorial

Scan the QR code below for the HEI ReBot Lift assembly and debugging tutorial.
The shared tutorial complements this hardware package; verify part revisions,
wiring, limits, emergency stop, and first-motion checks against the repository.

<p align="center">
  <a href="../media/hei-rebot-lift-assembly-debugging-tutorial.png">HEI ReBot Lift assembly and debugging tutorial QR code</a>
</p>

## 🧭 Recommended Reproduction Order

1. Open [Hei_robot_lift.STEP](Hei_robot_lift.STEP) to understand the full robot structure.
2. Use [HEI_ReBot_Lift_BOM.md](HEI_ReBot_Lift_BOM.md) / [xlsx](HEI_ReBot_Lift_BOM.xlsx) to prepare motors, electronics, sensors, fasteners, power parts, cables, cameras, and other purchased parts.
3. Review [Metal_Parts/HEI_Metal_Body_Parts_List.xlsx](Metal_Parts/HEI_Metal_Body_Parts_List.xlsx) before sending metal parts for machining.
4. Use `Metal_Parts/step/` and `Metal_Parts/dwg/` together when communicating with the manufacturer.
5. Print the STL files in [3D_Printed_Parts/](3D_Printed_Parts/) and test-fit them before final assembly.
6. Assemble the chassis, lift, dual arms, cameras, wiring, and emergency-stop/power system.
7. After assembly, continue with the software-side checks: motor IDs, port binding, lift homing, chassis direction, arm zero position, and camera streams.

## 🦾 Arm Hardware Reference

The dual arms follow the open-hardware spirit of [Seeed reBot-DevArm](https://github.com/Seeed-Projects/reBot-DevArm), while HEI ReBot Lift extends the system into a mobile dual-arm platform with lift and real-robot learning workflows.

| Item | Current Configuration | Notes |
| --- | --- | --- |
| Arm count | 2 | Left and right arms |
| DOF per arm | 6 DOF + 1 gripper | 6 arm joints and one gripper motor |
| Joints 1-3 | DM4340P series | Higher-load shoulder/elbow joints |
| Joints 4-6 | DM4310 series | Wrist joints, tuned separately in software |
| Gripper | DM4310 series | Open/close control |
| Communication | U2CAN | Separate driver boards/ports are used by the system |
| Main control mode | Position control | LeRobot actions use joint position targets |

## ⬆️ Lift Platform

The lift platform expands the working height of the dual arms. In the software stack, the lift homes to the upper limit during startup and defines the upper limit as `height.pos = 0`.

| Item | Current Configuration | Notes |
| --- | --- | --- |
| Mechanism | Lead-screw lift platform | Related files are included in printed and metal parts |
| Motor | DM4310 series | Lift motor, controlled through U2CAN |
| Position range | -700 mm to 0 mm | Upper limit is 0; downward motion is negative |
| Control interface | Position target | LeRobot action key: `height.pos` |
| Homing | Upper limit switch | Required before reliable height control |

## 🛞 Four-Wheel O-Type Omnidirectional Base

The chassis supports translation and rotation for mobile manipulation tasks.

| Item | Current Configuration | Notes |
| --- | --- | --- |
| Base type | Four-wheel O-type omnidirectional chassis | Supports forward/backward, lateral, and yaw motion |
| Wheel motors | 4 x DM4310 series | Four chassis motors are configured as DM4310 in software |
| Control interface | Velocity control | `x.vel`, `y.vel`, `theta.vel` |
| Smoothing | Acceleration/deceleration limit | Reduces shaking during start and stop |

## 🖨️ 3D Printed Parts

Current release: **24 STL files**. The revised files and chassis-copy naming are
documented under [Release Updates](#release-updates).

Typical groups include:

- Base/chassis printed parts: `part_dipan_*`
- Lift platform printed parts: `part_shengjiang_*`, `part_shengjiang_pingtai_*`
- Battery/case parts: `part_dianchi_ke_*`, `part_waike_7`
- Camera parts: `part_xiangji_*`
- Motor/bracket printed parts: `part_danpan_dm_zhijia_dayin*`

Printing notes:

- Print one set first for fit checking before batch printing.
- Check screw holes, cable clearance, motor mounting direction, and camera angle before final assembly.
- Material and infill should be selected according to the actual load and mounting position.

## 🧱 Metal / CNC / Sheet-Metal Parts

Current release:

| Type | Count | Directory |
| --- | ---: | --- |
| STEP | 11 | [Metal_Parts/step/](Metal_Parts/step/) |
| DWG | 9 | [Metal_Parts/dwg/](Metal_Parts/dwg/) |
| Metal list | 1 | [Metal_Parts/HEI_Metal_Body_Parts_List.xlsx](Metal_Parts/HEI_Metal_Body_Parts_List.xlsx) |

Metal STEP files:

- `cnc-DM_4340P_banjin_falan.STEP`
- `cnc-part_shengjiang_falan.STEP`
- `part_danpan_dm_zhijia.STEP`
- `part_dipan_1.STEP`
- `part_shengjiang_falan_zhijia.STEP`
- `part_waike_2.STEP`
- `part_waike_3.STEP`
- `part_waike_5.STEP`
- `part_yaobu_1.STEP`
- `part_yaobu_2.STEP`
- `part_yaobu_3.STEP`

DWG files are provided for manufacturing communication and drawing review. Please verify tolerances, bending direction, surface treatment, hole size, and threaded holes with your manufacturer before production.

## 📷 Cameras and Sensors

The software side currently supports a multi-camera setup, typically:

```text
front       head/front camera
left_wrist  left wrist camera
right_wrist right wrist camera
```

For USB cameras, MJPG is recommended to reduce bandwidth usage and improve stability. The current checkout does not contain the previously discussed standalone D435 examples; do not treat them as part of this deployment. For the current camera configuration, see the [driver guide](../software/lerobot-hei-rebot-lift/src/lerobot/robots/hei_rebot_lift/README.md#camera-configuration).

## ✅ Hardware Checklist Before Power-On

- [ ] The full assembly has been reviewed using [Hei_robot_lift.STEP](Hei_robot_lift.STEP)
- [ ] Purchased parts match [HEI_ReBot_Lift_BOM.md](HEI_ReBot_Lift_BOM.md) / [xlsx](HEI_ReBot_Lift_BOM.xlsx)
- [ ] Metal parts match the metal list and CAD files
- [ ] 3D printed parts are test-fitted before final assembly
- [ ] Left/right arm zero positions are mechanically safe
- [ ] Both lift limit switches and their IO states work reliably
- [ ] Chassis wheel direction and motor ID mapping are correct
- [ ] Emergency stop and power distribution are checked
- [ ] USB/CAN/serial cables are fixed and strain-relieved
- [ ] Cameras stream reliably before robot motion tests

## ⚠️ Notes

- The BOM, CAD files, and drawings are released for reproduction reference. Please re-check stock, price, mechanical tolerances, motor versions, and electrical compatibility before purchasing or machining.
- Keep enough physical clearance during first power-on and first motion tests.
- For the latest motor parameters, port mapping, camera configuration, and control commands, use the software documentation as the source of truth.

## 🙏 References

- [Seeed reBot-DevArm](https://github.com/Seeed-Projects/reBot-DevArm): open robotic arm hardware and reproducible embodied AI hardware documentation.
- [LeRobot](https://github.com/huggingface/lerobot): robot interface, dataset format, training, and real-robot policy deployment ecosystem.

## Chinese Version

- [README_zh.md](README_zh.md)

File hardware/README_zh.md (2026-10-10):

# HEI ReBot Lift Hardware

[English](README.md) | [中文](README_zh.md)

本目录是 **HEI ReBot Lift** 的硬件资料包，用于复现一台 **双臂 + 升降平台 + 四轮 O 型全向底盘** 的移动操作机器人。

这个目录的目标不是只放几个模型文件，而是尽量把复现真实机器人需要的资料整理清楚：采购、加工、3D 打印、装配检查、后期维护都能有对应入口。

## 版本更新记录

### 2026-09-21

本次将整机 BOM 升级到 V1.1，更新整机总装模型，并重新整理打印件发布。大部分
文件继续沿用原有路径；底盘副本使用下表中的当前名称：

| 更新文件 | 变更内容 |
| --- | --- |
| [HEI_ReBot_Lift_BOM.md](HEI_ReBot_Lift_BOM.md) / [xlsx](HEI_ReBot_Lift_BOM.xlsx) | 更新到 BOM V1.1；Markdown 总价由 Excel 公式重算后重新生成 |
| [Hei_robot_lift.STEP](Hei_robot_lift.STEP) | 替换为最新整机 STEP 总装模型 |
| [part_dianchi_ke_1.STL](3D_Printed_Parts/part_dianchi_ke_1.STL) | 更新电池外壳打印件 1 |
| [part_dianchi_ke_2.STL](3D_Printed_Parts/part_dianchi_ke_2.STL) | 更新电池外壳打印件 2 |
| [part_dipan_3-1.STL](3D_Printed_Parts/part_dipan_3-1.STL) | 更新底盘打印件 3-1 |
| [part_dipan_3_2.STL](3D_Printed_Parts/part_dipan_3_2.STL) | 当前底盘打印件 3，第 2 份 |
| [part_dipan_3_3.STL](3D_Printed_Parts/part_dipan_3_3.STL) | 当前底盘打印件 3，第 3 份 |
| [part_dipan_3_4.STL](3D_Printed_Parts/part_dipan_3_4.STL) | 当前底盘打印件 3，第 4 份 |

旧的 `part_dipan_3.STL` 和连字符命名的 `part_dipan_3-2/-3/-4.STL` 已移除。
三个下划线命名文件按设计具有相同模型，表示需要打印三份实体，不是三种不同结构。

加工或打印前请重新下载这些文件。此前已经打印的零件不一定与最新版总装完全
匹配，复用前应在新 STEP 模型中检查配合面、孔位和装配间隙。

## 📁 目录结构

```text
hardware/
├── README.md                         # 英文硬件说明
├── README_zh.md                      # 中文硬件说明
├── HEI_ReBot_Lift_BOM.md                        # GitHub 可直接浏览的 BOM 表格
├── HEI_ReBot_Lift_BOM.xlsx                      # 原始可编辑 BOM 表格
├── Hei_robot_lift.STEP               # 整体机器人 STEP 总装模型
├── 3D_Printed_Parts/                 # 3D 打印件 STL
└── Metal_Parts/
    ├── HEI_Metal_Body_Parts_List.xlsx       # 金属主体加工件清单
    ├── step/                         # 金属 / CNC / 钣金件 STEP
    └── dwg/                          # 金属加工件 DWG 图纸
```

## 🧾 核心文件

| 文件 | 用途 | 说明 |
| --- | --- | --- |
| [HEI_ReBot_Lift_BOM.md](HEI_ReBot_Lift_BOM.md) / [xlsx](HEI_ReBot_Lift_BOM.xlsx) | 整机总 BOM V1.1 | Markdown 用于在线查看，Excel 用于编辑维护；采购前重新核对实时价格 |
| [Hei_robot_lift.STEP](Hei_robot_lift.STEP) | 整机总装模型 | 建议优先打开，用来理解整机结构、空间布局和装配关系 |
| [Metal_Parts/HEI_Metal_Body_Parts_List.xlsx](Metal_Parts/HEI_Metal_Body_Parts_List.xlsx) | 金属件清单 | 与 `Metal_Parts/step/`、`Metal_Parts/dwg/` 配合给加工厂使用 |
| [3D_Printed_Parts/](3D_Printed_Parts/) | 3D 打印件 | 包含外壳、支架、升降、底盘、相机等相关 STL 文件 |
| [Metal_Parts/step/](Metal_Parts/step/) | 金属件 STEP | 用于加工沟通、三维检查和装配确认 |
| [Metal_Parts/dwg/](Metal_Parts/dwg/) | 金属件 DWG | 用于二维图纸检查和加工沟通 |

## 组装与调试教程

扫描下方二维码查看 HEI ReBot Lift 组装与调试教程。外部共享教程作为硬件资料包
的补充；实际装配时仍需以仓库中的零件版本、接线、限位、急停和首次运动检查为准。

<p align="center">
  <a href="../media/hei-rebot-lift-assembly-debugging-tutorial.png">HEI ReBot Lift 组装与调试教程二维码</a>
</p>

## 🧭 推荐复现顺序

1. 先打开 [Hei_robot_lift.STEP](Hei_robot_lift.STEP)，理解整机结构和空间关系。
2. 根据 [HEI_ReBot_Lift_BOM.md](HEI_ReBot_Lift_BOM.md) / [xlsx](HEI_ReBot_Lift_BOM.xlsx) 准备电机、电控、传感器、相机、电源、线材、紧固件等物料。
3. 加工金属件前，先核对 [Metal_Parts/HEI_Metal_Body_Parts_List.xlsx](Metal_Parts/HEI_Metal_Body_Parts_List.xlsx)。
4. 给加工厂沟通时，建议 `Metal_Parts/step/` 和 `Metal_Parts/dwg/` 一起提供。
5. 打印 [3D_Printed_Parts/](3D_Printed_Parts/) 中的 STL 文件，建议先小批量试装，再批量打印。
6. 依次完成底盘、升降平台、双臂、相机、走线、电源和急停系统装配。
7. 装配完成后，再进入软件侧检查：电机 ID、端口绑定、升降 homing、底盘方向、机械臂零位和相机画面。

## 🦾 机械臂硬件参考

机械臂部分参考了 [Seeed reBot-DevArm](https://github.com/Seeed-Projects/reBot-DevArm) 的开源思路。HEI ReBot Lift 在此基础上扩展为双臂移动操作平台，并接入 LeRobot 数据采集、ACT/VLA 训练和真实机器人推理流程。

| 项目 | 当前配置 | 说明 |
| --- | --- | --- |
| 机械臂数量 | 2 | 左右双臂 |
| 每臂自由度 | 6 DOF + 1 Gripper | 6 个关节 + 夹爪 |
| 关节 1-3 | DM4340P 系列 | 主要承担肩部、肘部等大负载关节 |
| 关节 4-6 | DM4310 系列 | 主要承担腕部关节，软件中单独调参 |
| 夹爪 | DM4310 系列 | 夹爪开合控制 |
| 通信 | U2CAN | 系统中左右臂使用独立驱动板/端口 |
| 主要控制方式 | 位置控制 | LeRobot action 使用关节位置目标 |

## ⬆️ 升降平台

升降平台用于扩展双臂工作高度。软件侧启动后会先回上限位，并将上限位定义为 `height.pos = 0`。

| 项目 | 当前配置 | 说明 |
| --- | --- | --- |
| 机构形式 | 丝杆升降平台 | 相关结构件包含在 3D 打印件和金属件中 |
| 电机 | DM4310 系列 | 升降电机，通过 U2CAN 控制 |
| 位置范围 | -700 mm 到 0 mm | 上限位为 0，向下为负值 |
| 控制接口 | 位置目标 | LeRobot action key 为 `height.pos` |
| 回零方式 | 上限位开关 | 准确高度控制前必须先 homing |

## 🛞 四轮 O 型全向底盘

底盘用于移动操作任务中的平移和旋转。

| 项目 | 当前配置 | 说明 |
| --- | --- | --- |
| 底盘形式 | 四轮 O 型全向底盘 | 支持前后、左右和旋转 |
| 轮组电机 | 4 x DM4310 系列 | 软件中四个底盘电机均配置为 DM4310 |
| 控制接口 | 速度控制 | `x.vel`、`y.vel`、`theta.vel` |
| 平滑方式 | 加减速限制 | 降低启动、停止时的整机晃动 |

## 🖨️ 3D 打印件

当前包含 **24 个 STL 文件**。修订文件和底盘副本命名详见
[版本更新记录](#版本更新记录)。

典型分类：

- 底盘相关：`part_dipan_*`
- 升降平台相关：`part_shengjiang_*`、`part_shengjiang_pingtai_*`
- 电池 / 外壳相关：`part_dianchi_ke_*`、`part_waike_7`
- 相机相关：`part_xiangji_*`
- 电机 / 支架相关：`part_danpan_dm_zhijia_dayin*`

打印建议：

- 先打印一套关键件试装，再批量打印。
- 重点检查螺丝孔、走线空间、电机安装方向和相机角度。
- 材料和填充率根据实际受力位置选择，不建议关键承力位置随意降低强度。

## 🧱 金属 / CNC / 钣金件

当前包含：

| 类型 | 数量 | 目录 |
| --- | ---: | --- |
| STEP | 11 | [Metal_Parts/step/](Metal_Parts/step/) |
| DWG | 9 | [Metal_Parts/dwg/](Metal_Parts/dwg/) |
| 金属件清单 | 1 | [Metal_Parts/HEI_Metal_Body_Parts_List.xlsx](Metal_Parts/HEI_Metal_Body_Parts_List.xlsx) |

金属 STEP 文件包括：

- `cnc-DM_4340P_banjin_falan.STEP`
- `cnc-part_shengjiang_falan.STEP`
- `part_danpan_dm_zhijia.STEP`
- `part_dipan_1.STEP`
- `part_shengjiang_falan_zhijia.STEP`
- `part_waike_2.STEP`
- `part_waike_3.STEP`
- `part_waike_5.STEP`
- `part_yaobu_1.STEP`
- `part_yaobu_2.STEP`
- `part_yaobu_3.STEP`

DWG 文件用于加工沟通和二维图纸检查。正式加工前，请和加工厂确认公差、折弯方向、表面处理、孔径、沉孔、螺纹孔等细节。

## 📷 相机与传感器

软件侧支持多相机配置，常见配置为：

```text
front       头部 / 前视相机
left_wrist  左腕相机
right_wrist 右腕相机
```

USB 相机建议使用 `MJPG` 格式，降低 USB 带宽占用，提高多相机同时采集稳定性。当前仓库不包含之前讨论的 D435 独立示例，不应按该目录部署；当前相机配置请看
[驱动说明](../software/lerobot-hei-rebot-lift/src/lerobot/robots/hei_rebot_lift/README_zh.md#相机配置)。

## ✅ 上电前硬件检查清单

- [ ] 已使用 [Hei_robot_lift.STEP](Hei_robot_lift.STEP) 检查整机装配关系
- [ ] 外购件已根据 [HEI_ReBot_Lift_BOM.md](HEI_ReBot_Lift_BOM.md) / [xlsx](HEI_ReBot_Lift_BOM.xlsx) 核对
- [ ] 金属件已对照清单和 CAD 文件确认
- [ ] 3D 打印件已完成试装
- [ ] 左右臂机械零位处于安全位置
- [ ] 升降平台上下限位开关与 IO 状态均可可靠触发
- [ ] 底盘四轮方向和电机 ID 映射正确
- [ ] 急停和电源分配检查正常
- [ ] USB / CAN / 串口线材固定可靠，有基本应力释放
- [ ] 相机画面稳定后再进行机器人运动测试

## ⚠️ 注意事项

- BOM、CAD 和图纸主要作为复现参考，正式采购和加工前请重新核对库存、价格、机械公差、电机版本和电气兼容性。
- 第一次上电、第一次运动和第一次升降测试时，机器人周围必须预留足够安全空间。
- 电机参数、端口映射、相机配置和控制命令以 software 目录中的最新程序和文档为准。

## 🙏 参考项目

- [Seeed reBot-DevArm](https://github.com/Seeed-Projects/reBot-DevArm)：开放机械臂硬件、BOM、软件生态和可复现具身智能硬件文档。
- [LeRobot](https://github.com/huggingface/lerobot)：机器人接口、数据集格式、训练和真实机器人策略部署生态。

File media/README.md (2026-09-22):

# Media

[English](README.md) | [中文](README_zh.md)

README illustrations and robot demonstration assets live here.

| Asset | Purpose |
| --- | --- |
| [Repository-Header-Image.jpg](Repository-Header-Image.jpg) | Project homepage header |
| [7.jpg](7.jpg) | Robot showcase photo |
| [hei-robot-lift-play.gif](hei-robot-lift-play.gif) | Robot demonstration |
| [robot-mujoco.png](robot-mujoco.png) | Complete-model VR simulation overview |
| [arm_zero.png](arm_zero.png) | Designed mechanical zero posture reference for both arms |
| [hei-rebot-lift-assembly-debugging-tutorial.png](hei-rebot-lift-assembly-debugging-tutorial.png) | QR code for the assembly and debugging tutorial |
| [META-QUEST-BUTTON.jpg](META-QUEST-BUTTON.jpg) | Right-controller system button for headset recentering |
| [META-GRIP-BUTTON.jpg](META-GRIP-BUTTON.jpg) | Side grip buttons |
| [META-FRONT-TRIGGER.jpg](META-FRONT-TRIGGER.jpg) | Front triggers |
| [star-history-2026731.png](star-history-2026731.png) | Static Star History snapshot, not a live-updating chart |

Controller instructions and the **hold Meta Quest for about 3 seconds to
recenter** reminder belong in the [VR guide](../software/lerobot-hei-rebot-lift/examples/hei_rebot_lift/VR_mujoco_ik/README.md#vr-controller-tutorial).
The community QR code is maintained separately under `community/`.
Keep image links relative so they work after cloning to another machine.

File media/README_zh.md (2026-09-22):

# 展示素材

[English](README.md) | [中文](README_zh.md)

这里保存 README 插图和机器人演示素材。

| 素材 | 用途 |
| --- | --- |
| [Repository-Header-Image.jpg](Repository-Header-Image.jpg) | 项目主页宣传图 |
| [7.jpg](7.jpg) | 机器人展示照片 |
| [hei-robot-lift-play.gif](hei-robot-lift-play.gif) | 功能演示 |
| [robot-mujoco.png](robot-mujoco.png) | 完整模型 VR 仿真概览 |
| [arm_zero.png](arm_zero.png) | 双臂设计机械零位姿态参考 |
| [hei-rebot-lift-assembly-debugging-tutorial.png](hei-rebot-lift-assembly-debugging-tutorial.png) | 组装与调试教程二维码 |
| [META-QUEST-BUTTON.jpg](META-QUEST-BUTTON.jpg) | 右手柄系统按钮，用于头显重新居中 |
| [META-GRIP-BUTTON.jpg](META-GRIP-BUTTON.jpg) | 侧面握把按钮 |
| [META-FRONT-TRIGGER.jpg](META-FRONT-TRIGGER.jpg) | 前扳机 |
| [star-history-2026731.png](star-history-2026731.png) | Star History 静态截图，不会实时刷新 |

手柄操作及**长按 Meta Quest 约 3 秒重新校准**的提醒统一见
[VR 教程](../software/lerobot-hei-rebot-lift/examples/hei_rebot_lift/VR_mujoco_ik/README_zh.md#vr-手柄使用教程)。
社区二维码单独放在 `community/`。图片使用相对链接，方便更换电脑后部署。

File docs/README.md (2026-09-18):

# HEI ReBot Lift Documentation

[English](README.md) | [中文](README_zh.md)

## Start Here

Follow this order: prepare hardware, deploy environments, test pure simulation,
verify hardware independently, test real teleoperation, record data, then train
and run a policy. Real startup automatically homes the lift; clear the workspace
and keep the emergency stop reachable.

| Topic | Guide | Contents |
| --- | --- | --- |
| Project and quick setup | [Project README](../README.md) | Hardware overview, environments, startup order |
| Hardware reproduction | [Hardware guide](../hardware/README.md) | BOM, full STEP assembly, printed and metal parts |
| Robot configuration | [Driver guide](../software/lerobot-hei-rebot-lift/src/lerobot/robots/hei_rebot_lift/README.md) | Device mapping, motor parameters, lift units, watchdog |
| VR deployment and use | [VR + MuJoCo IK](../software/lerobot-hei-rebot-lift/examples/hei_rebot_lift/VR_mujoco_ik/README.md) | Pinocchio/CasADi installation, controller inputs, safe arming, troubleshooting |
| Model and controller entry points | [MuJoCo IK guide](../software/lerobot-hei-rebot-lift/examples/hei_rebot_lift/VR_mujoco_ik/mujoco_ik/README.md) | Complete-model simulation/real mode, legacy dual-arm entry, self-checks |
| Debugging and data collection | [Examples guide](../software/lerobot-hei-rebot-lift/examples/hei_rebot_lift/README.md) | Port binding, lift/chassis tests, recording, resume, cleanup |
| Training and inference | [Examples guide](../software/lerobot-hei-rebot-lift/examples/hei_rebot_lift/README.md) | ACT/SmolVLA, checkpoint paths, replay, evaluate, rollout |
| Reproduction and collaboration | [Community](../community/README.md) | WeChat group, contact details, QR code |
| Jetson system icon troubleshooting | [Missing-icon repair record](jetson_system_icons.md) | SVG decoding, interrupted dpkg configuration, recovery and prevention |

## README Map and Maintenance

Each guide has a different scope; synchronization means matching instructions
and shared facts, not copying the entire homepage into every submodule.

| Location (from repository root) | English | Chinese | Scope |
| --- | --- | --- | --- |
| Repository root | [README.md](../README.md) | [README_zh.md](../README_zh.md) | First deployment, simulation practice, real startup; also [French](../README_Fr.md) and [Spanish](../README_es.md) |
| `hardware/` | [Guide](../hardware/README.md) | [Guide](../hardware/README_zh.md) | BOM, CAD, assembly and power-on checks |
| `docs/` | [Index](README.md) | [Index](README_zh.md) | Documentation navigation and maintenance |
| `community/` | [Guide](../community/README.md) | [Guide](../community/README_zh.md) | Contact details and group QR code |
| `media/` | [Guide](../media/README.md) | [Guide](../media/README_zh.md) | Images, GIFs, controller diagrams and static Star History |
| Software root | [Guide](../software/lerobot-hei-rebot-lift/README.md) | [Guide](../software/lerobot-hei-rebot-lift/README_zh.md) | Software module navigation; deployment links to the homepage |
| HEI examples | [Guide](../software/lerobot-hei-rebot-lift/examples/hei_rebot_lift/README.md) | [Guide](../software/lerobot-hei-rebot-lift/examples/hei_rebot_lift/README_zh.md) | Debugging, recording, datasets, training, replay/evaluate/rollout |
| VR/IK root | [Guide](../software/lerobot-hei-rebot-lift/examples/hei_rebot_lift/VR_mujoco_ik/README.md) | [Guide](../software/lerobot-hei-rebot-lift/examples/hei_rebot_lift/VR_mujoco_ik/README_zh.md) | VR environment, controller tutorial, simulation and real bridge |
| Telegrip | [Guide](../software/lerobot-hei-rebot-lift/examples/hei_rebot_lift/VR_mujoco_ik/telegrip/README.md) | [Guide](../software/lerobot-hei-rebot-lift/examples/hei_rebot_lift/VR_mujoco_ik/telegrip/README_zh.md) | WebXR bridge and image-display configuration |
| MuJoCo IK | [Guide](../software/lerobot-hei-rebot-lift/examples/hei_rebot_lift/VR_mujoco_ik/mujoco_ik/README.md) | [Guide](../software/lerobot-hei-rebot-lift/examples/hei_rebot_lift/VR_mujoco_ik/mujoco_ik/README_zh.md) | Complete-model vs. legacy entries and offline tests |
| Complete URDF model | [Guide](../software/lerobot-hei-rebot-lift/examples/hei_rebot_lift/VR_mujoco_ik/mujoco_ik/model/HEI_robot_urdf/README.md) | [Guide](../software/lerobot-hei-rebot-lift/examples/hei_rebot_lift/VR_mujoco_ik/mujoco_ik/model/HEI_robot_urdf/README_zh.md) | Joint inspection, visualization, TCP/gripper conventions, MJCF export |
| Robot driver | [Guide](../software/lerobot-hei-rebot-lift/src/lerobot/robots/hei_rebot_lift/README.md) | [Guide](../software/lerobot-hei-rebot-lift/src/lerobot/robots/hei_rebot_lift/README_zh.md) | Device config, protocol units, motor parameters, homing and watchdog |

When changing installation or startup, update all four homepages. When changing
controller behavior, update the VR guide pair and homepage controller summaries.
When changing driver defaults, update the driver guide pair and any numerical
examples in the VR/homepage guides. Source code and `environment.yml` take
precedence over copied documentation values.

General LeRobot policy, Docker, and other-robot READMEs remain outside this HEI
guide set. The previously discussed standalone D435/audio examples are not in
this checkout and are not advertised as available deployment steps.

## Important Conventions

- Follow each guide's working-directory instructions; paths are relative, not tied to a particular home directory.
- Robot IP and computer IP are different settings. `--remote-ip` changes the LeRobot client connection; configure the VR camera endpoint separately in `telegrip/config.yaml`.
- Run only one robot command source. Stop teleoperation before recording; stop VR control and recording before replay or policy inference.
- Workspace projection and joint limits are not collision avoidance. The stable-grasp scene is a kinematic demonstration, not proof of physical grasp stability.
- Local data is not uploaded by default. Back up datasets before deleting episodes or changing camera schemas.

Additional assembly, wiring, and video tutorials can be linked here when available.

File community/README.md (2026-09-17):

# HEI ReBot Lift Community

[English](README.md) | [中文](README_zh.md)

Welcome to the HEI ReBot Lift community. This space is for discussing dual-arm mobile manipulation, VR teleoperation, LeRobot data collection, ACT/VLA training, real-robot deployment, and hardware reproduction.

## Join the WeChat Group

<p align="center">
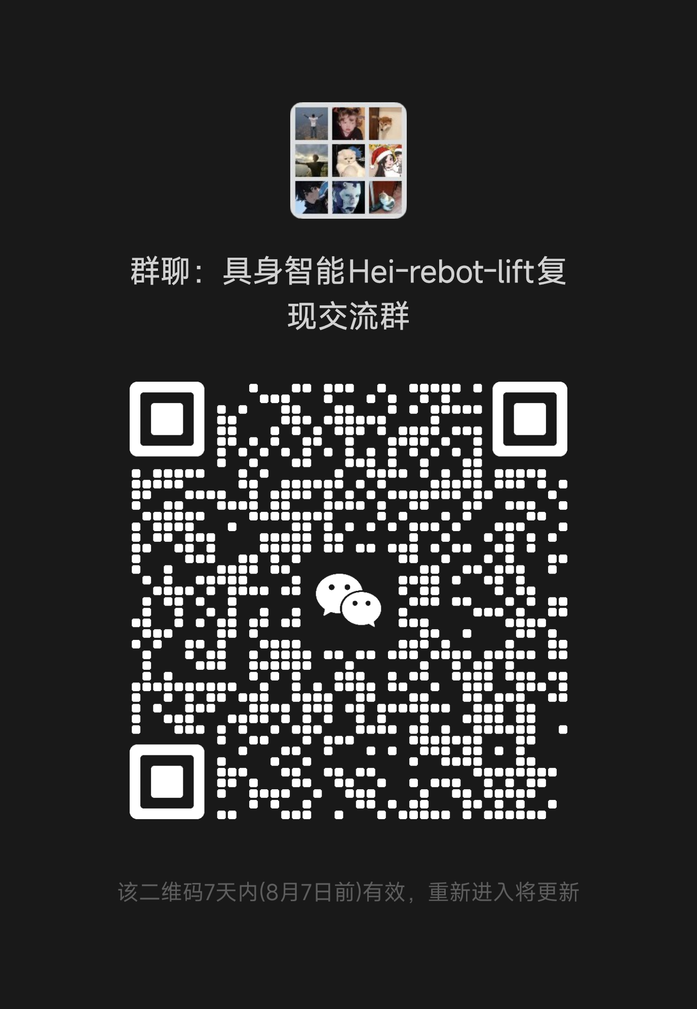
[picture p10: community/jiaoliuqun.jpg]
HEI ReBot Lift WeChat group QR code
  
</p>

If the QR code expires, add the WeChat account below and mention `HEI ReBot Lift`:

```text
hgm159951
```

## Contact

```text
WeChat community / collaboration: hgm159951
Email: hgm159951@163.com
```

GitHub Issues are also welcome for bug reports, reproduction notes, improvement suggestions, and real-robot test feedback.

## Topics

- HEI ReBot Lift reproduction, assembly, and debugging
- Damiao motors, U2CAN, lift platform, omnidirectional base, and camera setup
- VR teleoperation, MuJoCo/Pinocchio IK, and data collection
- LeRobotDataset, ACT, SmolVLA/VLA training, and real-robot rollout
- Teaching labs, algorithm validation, application deployment, and collaboration

## Chinese Version

- [README_zh.md](README_zh.md)

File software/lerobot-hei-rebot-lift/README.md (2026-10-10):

# HEI ReBot Lift Software

[English](README.md) | [中文](README_zh.md)

This is the runnable LeRobot-based software project for the dual-arm lifting
mobile robot. The repository-wide deployment guide lives two directories above.
**Do not follow a second, older installation procedure from this folder.**

## Start Here

1. Follow the [project setup guide](../../README.md#-quick-setup): install the robot-side `lerobot5`, computer-side `lerobot5`, and computer-side `hei-rebot-vr` dependencies according to their roles.
2. Practice with the [complete-model pure simulation](examples/hei_rebot_lift/VR_mujoco_ik/README.md#2a-test-vr-with-the-complete-robot-model) before connecting real hardware.
3. On the robot, bind serial ports and independently verify zeros, chassis, lift IO, and cameras using the [hardware tests](examples/hei_rebot_lift/README.md#1-hardware-check).
4. Follow the [real startup guide](../../README.md#-startup-flow), then record, train, and test using the examples below.

## Module Guides

| Module | Guide | Purpose |
| --- | --- | --- |
| Example programs | [Examples](examples/hei_rebot_lift/README.md) | Binding, independent tests, teleoperate, record/resume, dataset editing, ACT/SmolVLA, replay, evaluate, rollout |
| VR and simulation | [VR + MuJoCo IK](examples/hei_rebot_lift/VR_mujoco_ik/README.md) | Shared VR/IK environment, headset URL, Meta Quest calibration, controller inputs, real synchronization |
| Robot driver | [Driver](src/lerobot/robots/hei_rebot_lift/README.md) | Device/camera config, action/observation units, lift homing, motor gains and safety timeouts |
| Motor transport | [Damiao U2CAN source](src/lerobot/motors/damiao_u2can/) | Local motor communication implementation; independent of the old copied reference projects |
| All documentation | [Documentation index](../../docs/README.md) | Hardware, software, model, community, and language navigation |

## Working Directories and Safety

This directory is the **software root**. Commands beginning with
`PYTHONPATH=src` in the examples guide run here. VR wrappers run from
`examples/hei_rebot_lift/VR_mujoco_ik/` and activate `hei-rebot-vr` automatically.

- Headset URL uses the **computer IP**; client `--remote-ip` uses the **robot IP**.
- VR camera display is currently disabled in Telegrip, but host camera capture and recording remain enabled.
- The host automatically homes the lift upward. Check both limits and clear the path before starting.
- Only one robot command source may run at a time. Stop teleoperation before recording and stop VR real publishing before replay/evaluate/rollout.
- The arm zero tool writes zeros immediately; it is not a read-only diagnostic.
- The real bridge needs fresh VR and robot feedback plus both grips released. Do not bypass feedback to fix a connection fault.
- No-load simulation and IK guards do not establish collision avoidance or payload safety.

## LeRobot Foundation

This software tree is synchronized with **LeRobot 0.6.2**, upstream commit
`b9cb121cb7d4e3e26ec5c906d08dda68d151ba52` (2026-10-08). HEI-specific code
is kept in the robot, motor, and example modules listed above. See
[UPSTREAM.md](UPSTREAM.md) for the synchronization boundary and migration notes.

General LeRobot documentation remains under `docs/`, and policy-specific notes
under `docs/source/policy_*_README.md`. Those explain the underlying framework;
they do not replace the HEI hardware startup instructions. Respect the
[repository license](../../LICENSE) and third-party asset licenses.

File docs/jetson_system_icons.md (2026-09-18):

# Jetson System Icon Troubleshooting

[English](jetson_system_icons.md) | [中文](jetson_system_icons_zh.md) | [Documentation index](README.md)

Applies to Jetson, Ubuntu 22.04, ARM64, and the GNOME desktop. Recorded on 2026-09-18.
This guide covers missing Wi-Fi and file-manager button icons, not damaged photos,
camera frames, or robot control faults. It is a repair guide, not a mandatory setup step.

## 1. Incident and Conclusions

System icons turned into red crosses after environment installation.

| Observation | Interpretation |
| --- | --- |
| Icon theme was `Yaru` | The theme name was normal; this did not verify the files or decoder |
| Root disk was 93% full, with about 17 GB available | Not full when checked; earlier resource problems cannot be ruled out |
| `.bashrc` globally added an Anaconda library path under another user's home | A library conflict risk, but removing it alone did not visibly restore icons |
| SVG thumbnailing failed even with relevant environment variables removed | The system SVG decoding chain was malfunctioning, not just the current shell environment |
| apt reported `dpkg was interrupted` | An unfinished package configuration operation was confirmed |
| The user confirmed recovery after following the package-manager repair procedure | The procedure worked; complete logs are unavailable, so no single command can be identified as the sole fix |

**The best-supported explanation is an interrupted system package operation,
leaving configuration incomplete. SVG decoder installation or registration,
including its loader cache, may have been affected.** The exact interrupted
package, trigger, or initiating installation cannot be established from the
available logs. Power loss, cancellation, terminal closure, or a failed package
script are possibilities, not confirmed causes. There is no proof that the
project's Conda/pip commands directly damaged system files.

Icon rendering depends on theme files, the SVG plugin, the GdkPixbuf loader
cache, and desktop processes. Rebuilding the cache registers loaders; it does
not modify image content. See the [Ubuntu loader utility manual](https://manpages.ubuntu.com/manpages/jammy/man1/gdk-pixbuf-query-loaders.1.html).

## 2. Recovery Procedure

### 2.1 Stop the Robot and Inspect the System

Safely stop the host, teleoperation, replay, and debug tools. Support components
that could fall when disabled, save work, and ensure stable power. Wait for any
active apt/dpkg or software update task to finish. Do not remove lock files or
kill the package manager merely because it holds a lock.

Run these read-only checks from any directory:

```bash
df -h / /home
df -i / /home
sudo dpkg --audit
gsettings get org.gnome.desktop.interface icon-theme
printenv | grep -E 'LD_LIBRARY_PATH|LD_PRELOAD|GDK_PIXBUF|GTK_PATH|GTK_DATA_PREFIX'
grep -nE 'LD_LIBRARY_PATH|LD_PRELOAD|GDK_PIXBUF|GTK_PATH|GTK_DATA_PREFIX|anaconda|conda|source ' ~/.bashrc ~/.profile /etc/environment
```

No matching environment variables is not an error. Run `gsettings` in the
Jetson desktop terminal. If space or inodes are exhausted, free only data known
to be expendable, not system libraries, the dpkg database, or JetPack files.

### 2.2 Complete Interrupted Package Configuration First

If the audit reports unfinished configuration or apt displays:

```text
E: dpkg was interrupted, you must manually run 'sudo dpkg --configure -a' to correct the problem.
```

run:

```bash
sudo dpkg --configure -a
```

This completes all pending package configurations and associated triggers, not
just icon packages. Do not shut down or interrupt a normally progressing task.
On failure, retain the complete error and identify the failing package instead
of repeatedly forcing operations or removing NVIDIA packages.
See the [dpkg manual](https://manpages.ubuntu.com/manpages/jammy/man1/dpkg.1.html).

Only if broken dependencies are reported, inspect a simulated repair first:

```bash
sudo apt-get -s --fix-broken install
```

After reviewing the plan, repair and retry configuration:

```bash
sudo apt-get --fix-broken install
sudo dpkg --configure -a
```

**Stop if the plan removes NVIDIA, JetPack, CUDA, ROS, or many desktop packages.
Investigate repositories and dependencies first. Simulation does not change
the system; do not add automatic confirmation (`-y`) to the real repair.**
See the [APT repair and simulation options](https://manpages.ubuntu.com/manpages/jammy/man8/apt-get.8.html).

### 2.3 Reinstall Image Decoders if SVG Icons Still Fail

```bash
sudo apt update
sudo apt install --reinstall libgdk-pixbuf-2.0-0 librsvg2-2 librsvg2-common
```

Review the operation list before accepting it. A full OS upgrade or CUDA
reinstallation is not needed for this step. Even if icons recover now, verify
that package configuration is complete.

### 2.4 Rebuild the System Loader Cache

Use the Ubuntu 22.04 ARM64 system utility, not a tool from Conda:

```bash
sudo env -u LD_LIBRARY_PATH -u LD_PRELOAD \
  -u GDK_PIXBUF_MODULE_FILE -u GDK_PIXBUF_MODULEDIR \
  /usr/lib/aarch64-linux-gnu/gdk-pixbuf-2.0/gdk-pixbuf-query-loaders --update-cache
```

Success usually produces no output. On missing libraries, `undefined symbol`,
or a missing tool, retain the error; do not replace system `.so` files with
copies from another machine or use a Conda utility to update the system cache.

### 2.5 Verify SVG Decoding and Log In Again

```bash
env -u LD_LIBRARY_PATH -u LD_PRELOAD \
  -u GDK_PIXBUF_MODULE_FILE -u GDK_PIXBUF_MODULEDIR \
  /usr/bin/gdk-pixbuf-thumbnailer \
  /usr/share/icons/Adwaita/scalable/actions/go-previous-symbolic.svg \
  /tmp/jetson-icon-test-clean.png

file /tmp/jetson-icon-test-clean.png
sudo dpkg --audit
sudo apt-get check
```

Expect no SVG warning, `PNG image data` for the generated file, no outstanding
issues from the audit, and a successful dependency check. If the source icon
does not exist, use an existing system SVG before diagnosing decoder failure.

Save work, **log out of the desktop, and log in again**. Existing desktop
processes do not inherit changes made by `unset` or `source ~/.bashrc` in a
terminal. If package tools require a reboot, schedule it after configuration
has finished, not during installation.

## 3. If the Problem Persists

Check whether the SVG plugin exists and can be loaded:

```bash
ls -l /usr/lib/aarch64-linux-gnu/gdk-pixbuf-2.0/2.10.0/loaders/libpixbufloader-svg.so
env -u LD_LIBRARY_PATH -u LD_PRELOAD \
  -u GDK_PIXBUF_MODULE_FILE -u GDK_PIXBUF_MODULEDIR \
  /usr/lib/aarch64-linux-gnu/gdk-pixbuf-2.0/gdk-pixbuf-query-loaders \
  /usr/lib/aarch64-linux-gnu/gdk-pixbuf-2.0/2.10.0/loaders/libpixbufloader-svg.so
```

| Result | Next check |
| --- | --- |
| Plugin missing | Verify that `librsvg2-common` installed successfully |
| Missing dependency, symbol error, or load failure | Investigate library versions, `/usr/local/lib`, and global library paths; do not delete system libraries |
| Plugin loads but SVG thumbnailing fails | Check SVG cache registration, the actual icon file, and the complete error |
| SVG works but desktop icons remain broken | Verify a fresh login, the active theme, and desktop logs |

Reinstall themes only if their files are missing:

```bash
sudo apt install --reinstall adwaita-icon-theme yaru-theme-icon
```

Keep terminal output and inspect `/var/log/apt/history.log`,
`/var/log/apt/term.log`, and `/var/log/dpkg.log` to identify interrupted packages
and times. A Nautilus sharing warning about a missing `net` command does not
diagnose icon failure; installing Samba is not an icon fix. Clearing photo
thumbnail caches is not the repair for this system-icon incident.

## 4. Prevention

- Install project dependencies in separate Conda environments; do not use `sudo pip install` against system Python.
- Do not globally add Conda library directories in `.bashrc`, `.profile`, or `/etc/environment`. Remove obsolete injections such as the other-user Anaconda path seen in this incident.
- Back up startup files before editing. Remove only confirmed conflicting entries; retain normal Conda initialization and necessary ROS/CUDA paths. Do not globally clear Jetson library paths.
- Apply special library settings only to the process needing them, not to the desktop session. See [Conda's shared-library guidance](https://docs.conda.io/projects/conda-build/en/stable/resources/use-shared-libraries.html).
- Keep power, network, and terminals stable during apt/dpkg operations. For SSH maintenance, consider `tmux`; reconnect to an existing task rather than launching another installation.
- Check disk space and inodes before installing. This device was already 93% full; plan storage for datasets, models, and caches.
- Avoid blind `apt autoremove`, forced downgrades, mixing Ubuntu release repositories, or overwriting `/usr/lib`. Keep JetPack/NVIDIA repositories compatible with the device OS.

No Jetson system repair commands were executed remotely by the coding agent;
the recovery report came from the user's hardware test.

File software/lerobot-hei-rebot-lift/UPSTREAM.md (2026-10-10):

# LeRobot Upstream Baseline

This software tree is based on Hugging Face LeRobot:

- Version: `0.6.2`
- Upstream commit: `b9cb121cb7d4e3e26ec5c906d08dda68d151ba52`
- Upstream commit date: 2026-10-08
- Upstream repository: <https://github.com/huggingface/lerobot>

## HEI-Owned Modules

The following paths contain HEI ReBot Lift integrations and must be preserved
when synchronizing with a newer upstream revision:

- `src/lerobot/robots/hei_rebot_lift/`
- `src/lerobot/motors/damiao_u2can/`
- `examples/hei_rebot_lift/`
- the `hei_rebot_lift` dependency extra and `hei-rebot-lift-host` entry point in
  `pyproject.toml`
- the HEI registrations in `src/lerobot/robots/__init__.py` and
  `src/lerobot/robots/utils.py`

Local `datasets/`, `outputs/`, and MuJoCo runtime logs are generated artifacts
and are intentionally excluded from source control and upstream replacement.

## 0.6.2 Migration Notes

- Updated `lerobot.types` imports to `lerobot.lerobot_types`.
- Moved recording keyboard input to `lerobot.utils.keyboard_input`.
- Updated the HEI host to LeRobot's multipart ZMQ observation protocol. The HEI
  client still accepts legacy Base64 JSON observations for staged deployment.
- Preserved the 18-dimensional HEI state/action schema and three named camera
  features: `front`, `left_wrist`, and `right_wrist`.
- Removed obsolete generated requirements lock files; install from
  `pyproject.toml` extras so dependency versions follow the current baseline.

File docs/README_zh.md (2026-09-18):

# HEI ReBot Lift 文档导航

[English](README.md) | [中文](README_zh.md)

## 从这里开始

推荐顺序：准备硬件 → 部署环境 → 纯仿真验证 → 单模块硬件调试 → 真机遥操作 →
录制数据 → 训练与推理。真机启动会自动执行升降回零，请先清空工作区并确认急停可用。

| 主题 | 对应文档 | 内容 |
| --- | --- | --- |
| 项目与快速部署 | [项目主页](../README_zh.md) | 硬件概览、环境安装、整体启动顺序 |
| 硬件复现 | [硬件说明](../hardware/README_zh.md) | BOM、整机 STEP、打印件与金属加工件 |
| 机器人配置 | [驱动说明](../software/lerobot-hei-rebot-lift/src/lerobot/robots/hei_rebot_lift/README_zh.md) | 端口映射、电机参数、升降单位、看门狗 |
| VR 部署与操作 | [VR + MuJoCo IK](../software/lerobot-hei-rebot-lift/examples/hei_rebot_lift/VR_mujoco_ik/README_zh.md) | Pinocchio/CasADi 安装、手柄教程、安全解锁与排障 |
| 模型与控制入口 | [MuJoCo IK 说明](../software/lerobot-hei-rebot-lift/examples/hei_rebot_lift/VR_mujoco_ik/mujoco_ik/README_zh.md) | 完整模型仿真/真机、旧双臂入口、自检 |
| 调试与数据采集 | [示例使用教程](../software/lerobot-hei-rebot-lift/examples/hei_rebot_lift/README_zh.md) | 端口绑定、升降/底盘调试、录制、续录与清洗 |
| 训练与推理 | [示例使用教程](../software/lerobot-hei-rebot-lift/examples/hei_rebot_lift/README_zh.md) | ACT/SmolVLA、模型路径、回放、评估与 rollout |
| 交流与合作 | [社区](../community/README_zh.md) | 微信群、联系方式与二维码 |
| Jetson 系统图标排障 | [红叉图标修复记录](jetson_system_icons_zh.md) | SVG 解码、被中断的 dpkg 配置、修复流程与预防 |

## README 分布与维护

每份文档职责不同；“同步”是共同参数和操作流程一致，不是每个子目录都复制
完整主页。目前 12 个位置共 26 份 HEI README：中英各 12 份，另有法语/西语主页。

| 位置（相对项目根目录） | 英文 | 中文 | 职责 |
| --- | --- | --- | --- |
| 项目根目录 | [README.md](../README.md) | [README_zh.md](../README_zh.md) | 首次部署、仿真练习、真机启动；另有 [法语](../README_Fr.md)、[西语](../README_es.md) |
| `hardware/` | [说明](../hardware/README.md) | [说明](../hardware/README_zh.md) | BOM、CAD、装配、上电检查 |
| `docs/` | [导航](README.md) | [导航](README_zh.md) | 文档索引与维护约定 |
| `community/` | [说明](../community/README.md) | [说明](../community/README_zh.md) | 联系方式与群二维码 |
| `media/` | [说明](../media/README.md) | [说明](../media/README_zh.md) | 图片、GIF、手柄示意图与静态 Star History |
| 软件根目录 | [说明](../software/lerobot-hei-rebot-lift/README.md) | [说明](../software/lerobot-hei-rebot-lift/README_zh.md) | 软件模块导航，统一链接主页部署教程 |
| HEI examples | [说明](../software/lerobot-hei-rebot-lift/examples/hei_rebot_lift/README.md) | [说明](../software/lerobot-hei-rebot-lift/examples/hei_rebot_lift/README_zh.md) | 调试、录制、数据集、训练、回放/评估/推理 |
| VR/IK 根目录 | [说明](../software/lerobot-hei-rebot-lift/examples/hei_rebot_lift/VR_mujoco_ik/README.md) | [说明](../software/lerobot-hei-rebot-lift/examples/hei_rebot_lift/VR_mujoco_ik/README_zh.md) | VR 环境、手柄操作、仿真与真机桥接 |
| Telegrip | [说明](../software/lerobot-hei-rebot-lift/examples/hei_rebot_lift/VR_mujoco_ik/telegrip/README.md) | [说明](../software/lerobot-hei-rebot-lift/examples/hei_rebot_lift/VR_mujoco_ik/telegrip/README_zh.md) | WebXR 桥接与图像显示配置 |
| MuJoCo IK | [说明](../software/lerobot-hei-rebot-lift/examples/hei_rebot_lift/VR_mujoco_ik/mujoco_ik/README.md) | [说明](../software/lerobot-hei-rebot-lift/examples/hei_rebot_lift/VR_mujoco_ik/mujoco_ik/README_zh.md) | 完整模型/旧入口区别、离线测试 |
| 完整 URDF 模型 | [说明](../software/lerobot-hei-rebot-lift/examples/hei_rebot_lift/VR_mujoco_ik/mujoco_ik/model/HEI_robot_urdf/README.md) | [说明](../software/lerobot-hei-rebot-lift/examples/hei_rebot_lift/VR_mujoco_ik/mujoco_ik/model/HEI_robot_urdf/README_zh.md) | 关节检查、可视化、TCP/夹爪约定、MJCF 导出 |
| 机器人驱动 | [说明](../software/lerobot-hei-rebot-lift/src/lerobot/robots/hei_rebot_lift/README.md) | [说明](../software/lerobot-hei-rebot-lift/src/lerobot/robots/hei_rebot_lift/README_zh.md) | 设备配置、协议单位、电机参数、回零与看门狗 |

改安装/启动流程时，同步四语言主页；改手柄行为时，同步 VR 中英教程及主页
手柄摘要；改驱动默认值时，同步驱动中英教程和 VR/主页中的相关数值示例。
代码及 `environment.yml` 优先于复制到文档的参数。

LeRobot 通用策略、Docker 与其他机器人 README 不在本 HEI 教程维护范围内。
之前讨论的 D435/语音独立示例不在当前仓库，不能作为已提供的部署步骤。

## 使用约定

- 遵循各教程的执行目录说明；使用相对路径，不依赖某台电脑的绝对目录。
- 机器人 IP 与电脑 IP 是两项配置。`--remote-ip` 只改变 LeRobot 客户端连接，相机显示地址需另改 `telegrip/config.yaml`。
- 同一时间只保留一个机器人控制源。录制前停止遥操作，回放/策略推理前停止 VR 控制与录制。
- 工作空间投影和关节限位不等于碰撞检测；稳定抓取场景是运动学演示，不代表真实接触抓取已经验证。
- 数据默认保存在本地。删除 episode 或变更相机字段前，请先备份数据。

后续装配、接线和视频教程整理完成后，可继续加入本导航。

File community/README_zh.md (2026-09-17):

# HEI ReBot Lift Community

[English](README.md) | [中文](README_zh.md)

欢迎加入 HEI ReBot Lift 社区，一起交流双臂移动操作、VR 遥操作、LeRobot 数据采集、ACT/VLA 训练、真实机器人部署和硬件复现经验。

## 加入微信交流群

<p align="center">
  HEI ReBot Lift 微信交流群二维码
</p>

如果二维码过期，可以添加微信号并备注 `HEI ReBot Lift`：

```text
hgm159951
```

## 联系我们

```text
微信社区 / 合作咨询：hgm159951
邮箱：hgm159951@163.com
```

也欢迎通过 GitHub Issue 反馈问题、记录复现过程、提交改进建议或分享实机测试结果。

## 适合交流的内容

- HEI ReBot Lift 复现、装配和调试
- 达妙电机、U2CAN、升降平台、全向底盘和相机配置
- VR 遥操作、MuJoCo/Pinocchio IK 和数据采集
- LeRobotDataset、ACT、SmolVLA/VLA 训练和实机推理
- 教学实验、算法验证、应用落地和合作开发

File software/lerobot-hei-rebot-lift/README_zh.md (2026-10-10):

# HEI ReBot Lift 软件

[English](README.md) | [中文](README_zh.md)

这里是双臂升降轮式机器人的 LeRobot 软件工程。整机部署教程位于上两级的项目
主页，**本目录不再重复维护另一套安装流程**，避免新旧步骤冲突。

## 从这里开始

1. 按 [项目部署教程](../../README_zh.md#-快速部署) 区分安装：机器人端 `lerobot5`、电脑控制/训练端 `lerobot5`、电脑 VR/IK 端 `hei-rebot-vr`。
2. 真机上手前先完成 [完整模型纯仿真练习](examples/hei_rebot_lift/VR_mujoco_ik/README_zh.md#2a-先用完整模型测试-vr-仿真)。
3. 在机器人端完成端口绑定，并按 [独立硬件测试](examples/hei_rebot_lift/README_zh.md#1-硬件检查) 检查零位、底盘、升降 IO 和相机。
4. 按 [真机启动流程](../../README_zh.md#-启动流程) 遥操作，再使用下方示例教程录制、训练与测试。

## 模块文档

| 模块 | 文档 | 功能 |
| --- | --- | --- |
| 示例程序 | [Examples](examples/hei_rebot_lift/README_zh.md) | 端口绑定、独立测试、遥操作、录制/续录、数据编辑、ACT/SmolVLA、回放、评估、推理 |
| VR 与仿真 | [VR + MuJoCo IK](examples/hei_rebot_lift/VR_mujoco_ik/README_zh.md) | 统一 VR/IK 环境、头显网址、Meta Quest 校准、手柄操作和真机同步 |
| 机器人驱动 | [Driver](src/lerobot/robots/hei_rebot_lift/README_zh.md) | 端口/相机配置、动作观测单位、升降回零、电机参数与安全超时 |
| 电机通信 | [Damiao U2CAN 源码](src/lerobot/motors/damiao_u2can/) | 项目内独立通信实现，不依赖以前复制进来的参考工程 |
| 全部教程 | [文档导航](../../docs/README_zh.md) | 硬件、软件、模型、社区与语言入口 |

## 执行目录与安全

这里是**软件根目录**。examples 教程中 `PYTHONPATH=src` 的命令在此执行；
VR 启动脚本在 `examples/hei_rebot_lift/VR_mujoco_ik/` 执行并自动激活
`hei-rebot-vr`。

- 头显网址填**电脑 IP**，客户端 `--remote-ip` 填**机器人 IP**。
- Telegrip 的 VR 图像回传当前关闭，但 host 相机采集和录制仍开启。
- host 启动会自动上行回零，先检查上下限位并清空路径。
- 同时只能有一个机器人控制源；录制前停遥操作，回放/评估/推理前停 VR 真机发布。
- 机械臂零位工具启动即写零位，不是只读诊断。
- 真机桥需要新鲜 VR 和实机反馈，并同时松开两侧握把解锁；不要绕过反馈解决网络问题。
- 仿真与 IK 防护不能证明碰撞检测或负载安全。

## 基于 LeRobot

当前软件底座已同步至 **LeRobot 0.6.2**，对应上游提交
`b9cb121cb7d4e3e26ec5c906d08dda68d151ba52`（2026-10-08）。HEI 自定义内容
集中在上表列出的机器人、电机和示例模块；同步边界与迁移说明见
[UPSTREAM.md](UPSTREAM.md)。

通用 LeRobot 文档保留在 `docs/`，策略说明位于
`docs/source/policy_*_README.md`；它们介绍底层框架，不替代 HEI 真机启动教程。
请遵守 [仓库许可证](../../LICENSE) 及第三方资源许可证。

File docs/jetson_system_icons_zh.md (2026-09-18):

# Jetson 系统图标红叉排障记录

[English](jetson_system_icons.md) | [中文](jetson_system_icons_zh.md) | [文档导航](README_zh.md)

适用环境：Jetson、Ubuntu 22.04、ARM64、GNOME 桌面。记录日期：2026-09-18。
本文处理 Wi-Fi、文件管理器返回按钮等系统图标缺失，不是相机画面、照片损坏或机器人控制故障。
这些是故障发生后的维护步骤，不是每次部署都要执行的安装命令。

## 1. 这次发生了什么

安装环境后，桌面右上角 Wi-Fi 和文件管理器按钮等图标变成红叉。

| 观察 | 能说明什么 |
| --- | --- |
| 当前图标主题是 `Yaru` | 主题名称看起来正常，但不能证明主题文件和解码组件完好 |
| 根分区占用 93%，仍有约 17 GB 可用 | 检查时没有占满；不能排除之前安装时发生过空间或其他资源问题 |
| `.bashrc` 全局加入另一个用户目录下的 Anaconda `lib` 路径 | 有动态库冲突风险，但单独移除它后未看到恢复，不能判定它是本次根因 |
| 清除相关环境变量后，SVG 图标测试仍提示无法识别格式 | 系统 SVG 解码链路存在异常，不只是当前终端环境问题 |
| 重装系统包时提示 `dpkg was interrupted` | 已确认包管理器存在未完成的配置操作 |
| 按恢复包管理器的流程处理后，用户确认图标恢复 | 此流程有效，但没有完整执行日志，不能认定某一条命令是唯一修复点 |

**最有证据支持的解释：此前系统包安装/配置中断，系统处于未完成配置状态；
SVG 加载器或其缓存可能因此没有正确安装、加载或注册，导致系统图标显示失败。**
具体是哪一次安装被中断、哪个包或触发器出了问题，现有日志不足以确定。
中断可能来自关机、终端关闭、手动取消或安装脚本失败，不能断定是项目中的
Conda/pip 安装命令直接破坏了系统。

系统图标加载大致经过：图标主题文件 → SVG 解码插件 → GdkPixbuf 加载器缓存 → 桌面程序。
任意一环异常都可能出现缺失图标。`gdk-pixbuf-query-loaders --update-cache`
用于重新注册加载器，不是修复图片内容。参见 [Ubuntu 工具说明](https://manpages.ubuntu.com/manpages/jammy/man1/gdk-pixbuf-query-loaders.1.html)。

## 2. 下次出现后的处理顺序

### 2.1 先停止机器人并检查状态

安全停止 host、遥操作、回放和调试程序，支撑可能失能下落的部件，再维护系统。
保存工作，保证供电稳定。确认没有另一项 apt/dpkg 或软件更新任务仍在运行；
若只是锁被占用，等待已有任务结束，不要删除锁文件或强杀包管理器。

以下只读命令可在任意目录执行：

```bash
df -h / /home
df -i / /home
sudo dpkg --audit
gsettings get org.gnome.desktop.interface icon-theme
printenv | grep -E 'LD_LIBRARY_PATH|LD_PRELOAD|GDK_PIXBUF|GTK_PATH|GTK_DATA_PREFIX'
grep -nE 'LD_LIBRARY_PATH|LD_PRELOAD|GDK_PIXBUF|GTK_PATH|GTK_DATA_PREFIX|anaconda|conda|source ' ~/.bashrc ~/.profile /etc/environment
```

`printenv` 的筛选没有输出，表示未发现这些变量，不一定是错误。
`gsettings` 建议在 Jetson 本机桌面终端执行。磁盘或 inode 耗尽时先释放已确认
可以清理的数据空间；不要删除 `/usr/lib`、dpkg 数据库或 JetPack 文件。

### 2.2 先恢复被中断的包配置

只有发现未完成配置或出现以下报错时，先做这一项：

```text
E: dpkg was interrupted, you must manually run 'sudo dpkg --configure -a' to correct the problem.
```

```bash
sudo dpkg --configure -a
```

该命令完成所有待配置包及相关触发器，不只配置图标包，可能需要一段时间。
正常运行期间不要关机或按 `Ctrl+C`。若失败，保留完整报错，先定位失败的包，
不要反复强制执行或卸载 NVIDIA 包。参见 [dpkg 手册](https://manpages.ubuntu.com/manpages/jammy/man1/dpkg.1.html)。

仅在提示依赖损坏时，先模拟查看修复计划：

```bash
sudo apt-get -s --fix-broken install
```

确认没有危险删除后，再执行：

```bash
sudo apt-get --fix-broken install
sudo dpkg --configure -a
```

**若计划删除 NVIDIA、JetPack、CUDA、ROS 或大量桌面包，停止并排查软件源和依赖。
模拟操作不改系统；实际操作不要加自动确认 `-y`。**
参见 [APT 修复与模拟选项](https://manpages.ubuntu.com/manpages/jammy/man8/apt-get.8.html)。

### 2.3 如果 SVG 图标仍有问题，重装解码组件

```bash
sudo apt update
sudo apt install --reinstall libgdk-pixbuf-2.0-0 librsvg2-2 librsvg2-common
```

检查 apt 操作列表，避免误删平台组件。不需要升级整个系统或重装 CUDA。
如果这一步已经恢复图标，也要检查包管理器状态，不能仅凭画面正常判断安装完整。

### 2.4 重建系统加载器缓存

下面是 Ubuntu 22.04 ARM64 的系统路径，不是 Conda 环境路径：

```bash
sudo env -u LD_LIBRARY_PATH -u LD_PRELOAD \
  -u GDK_PIXBUF_MODULE_FILE -u GDK_PIXBUF_MODULEDIR \
  /usr/lib/aarch64-linux-gnu/gdk-pixbuf-2.0/gdk-pixbuf-query-loaders --update-cache
```

正常通常没有输出。若报缺少依赖、`undefined symbol` 或工具不存在，先保留报错，
不要改用 Conda 内的同名工具，也不要从其他系统复制 `.so` 文件覆盖。

### 2.5 验证 SVG 解码，再重新登录

```bash
env -u LD_LIBRARY_PATH -u LD_PRELOAD \
  -u GDK_PIXBUF_MODULE_FILE -u GDK_PIXBUF_MODULEDIR \
  /usr/bin/gdk-pixbuf-thumbnailer \
  /usr/share/icons/Adwaita/scalable/actions/go-previous-symbolic.svg \
  /tmp/jetson-icon-test-clean.png

file /tmp/jetson-icon-test-clean.png
sudo dpkg --audit
sudo apt-get check
```

预期：SVG 测试不再警告，输出文件显示 `PNG image data`，`dpkg --audit` 没有
待处理异常，`apt-get check` 成功退出。测试图标路径不存在时不能据此判定
解码失败，需要换成系统中实际存在的 SVG 图标。

最后保存工作并**注销桌面、重新登录**，让 Wi-Fi 图标和文件管理器重新加载。
只在终端中 `unset` 或执行 `source ~/.bashrc`，不会更新已经运行的桌面进程。
若 dpkg/apt 表明需要重启，再安排重启；不要在配置操作未结束时重启。

## 3. 如果仍不恢复

直接检查 SVG 插件是否存在及能否加载：

```bash
ls -l /usr/lib/aarch64-linux-gnu/gdk-pixbuf-2.0/2.10.0/loaders/libpixbufloader-svg.so
env -u LD_LIBRARY_PATH -u LD_PRELOAD \
  -u GDK_PIXBUF_MODULE_FILE -u GDK_PIXBUF_MODULEDIR \
  /usr/lib/aarch64-linux-gnu/gdk-pixbuf-2.0/gdk-pixbuf-query-loaders \
  /usr/lib/aarch64-linux-gnu/gdk-pixbuf-2.0/2.10.0/loaders/libpixbufloader-svg.so
```

| 结果 | 下一步 |
| --- | --- |
| 插件不存在 | 检查 `librsvg2-common` 是否安装成功 |
| `not found` / `undefined symbol` / 加载失败 | 排查依赖版本、`/usr/local/lib` 或全局库路径；不要直接删系统库 |
| 插件正常，但 SVG 缩略图仍失败 | 检查缓存中的 SVG 注册项、实际图标文件及报错 |
| SVG 测试正常，但桌面仍红叉 | 确认已重新登录，检查实际使用的图标主题及桌面日志 |

仅在确认 Yaru/Adwaita 主题文件缺失时，重装主题：

```bash
sudo apt install --reinstall adwaita-icon-theme yaru-theme-icon
```

保存排障记录时附上完整终端输出，必要时查看 `/var/log/apt/history.log`、
`/var/log/apt/term.log` 和 `/var/log/dpkg.log`，确定中断的包与时间。
`Nautilus-Share-Message` 提到找不到 `net` 是共享功能提示，不等于图标解码失败，
不用为修图标专门安装 Samba。系统图标故障也不应通过删除照片缩略图缓存解决。

## 4. 避免再次发生

- 在独立 Conda 环境安装项目依赖，不使用 `sudo pip install` 修改系统 Python。
- 不将 Conda 的 `lib` 路径全局加入 `.bashrc`、`.profile` 或 `/etc/environment`；本次曾存在另一个用户目录的 Anaconda 路径，应删除这种遗留注入。
- 修改启动文件前备份；只删除已确认有问题的库路径项，保留正常 Conda 初始化块、必要的 ROS/CUDA 路径。不要全局清空 Jetson 库路径。
- 特定程序需要调整动态库环境时，只对该进程设置，不把 GDK/GTK 或 Conda 库变量导入整个桌面会话。[Conda 官方建议](https://docs.conda.io/projects/conda-build/en/stable/resources/use-shared-libraries.html)。
- apt/dpkg 安装时保持供电、网络和终端稳定；SSH 部署可使用 `tmux`，断线后重新连接查看任务，不要重复启动安装。
- 安装前检查空间和 inode；本次磁盘已使用 93%，应提前规划数据集、模型与缓存的存储空间。
- 不盲目执行 `apt autoremove`、强制降级、跨 Ubuntu 版本混用软件源或覆盖 `/usr/lib`；JetPack/NVIDIA 软件源应与设备系统匹配。

本记录没有远程执行 Jetson 系统修复命令；恢复结果来自用户实机反馈。

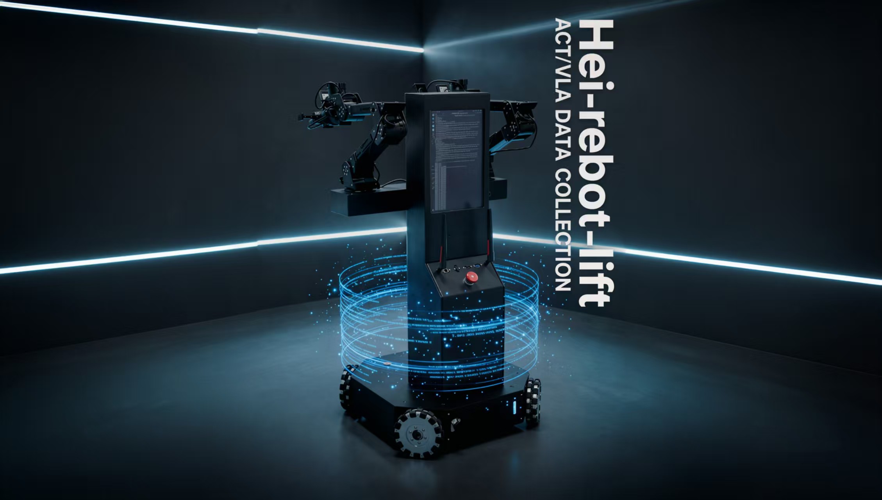
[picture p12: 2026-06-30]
media/Repository-Header-Image-1.jpg

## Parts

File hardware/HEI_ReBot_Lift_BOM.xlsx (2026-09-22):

类别 | 材料名称 | 型号 | 所需数量 | 单价 | 总价 | 采购链接
底盘部分 | 全向轮 | 【Omni B152】直径152mm全向轮*1个（含孔径6mm工业级抱紧式联轴器） | 4 | 229 |  | https://item.taobao.com/item.htm?id=692637585058
 | 轴承 | 6907（35*55*10） | 4 | 6 |  | https://item.taobao.com/item.htm?id=724149127063
 | 无刷电机 | DM-J4310-2ECV1.2 | 5 | 599 |  | https://item.taobao.com/item.htm?id=815333472865&from=cart&skuId=5965481553149&upStreamPrice=59900
 | 铝型材 | 100mm 两端攻丝M6欧标2020亮光氧化黑，臂厚1.5 | 10 | 3 |  | https://item.taobao.com/item.htm?id=17388859879
 | XT30单头线 | XT30U黄母V2版，14AWG(2.07平方)红黑线; 20cm | 3 | 9 |  | https://e.tb.cn/h.84Y2Y6OhkDc8Qd8?tk=0uragDI49y7 CZ193 「络黎XT30单头线XT30U转接线充电线带线插头延长线硅胶线特软软线」
 | XT30单头线 | XT30U黄母V2版，14AWG(2.07平方)红黑线; 50cm | 1 | 12 |  | https://e.tb.cn/h.84Y2Y6OhkDc8Qd8?tk=0uragDI49y7 CZ193 「络黎XT30单头线XT30U转接线充电线带线插头延长线硅胶线特软软线」
 | 电机连接线 | XT30(2+2)-F30厘米双母头延长线 | 6 | 15 |  | https://item.taobao.com/item.htm?id=822600109037
 | 电机连接线 | XT30(2+2)双母头35厘米正弯+直头 | 4 | 15 |  | https://item.taobao.com/item.htm?id=822600109037
升降部分 | 滑台模组GX | 1610丝杆800mm（找客服即可） | 1 | 429 |  | https://e.tb.cn/h.8exLaJE0rK9YDGT?tk=W1smgwOj0wZ CZ005 「含增票GX80双导轨直线滚珠丝杆滑台模组含57电机铝合金十字工作台」
 | 接近开关支架 | 单独支架 | 2 | 1 | 2 | https://e.tb.cn/h.8tJ2jyyiOJci8S7?tk=nQa7TkDqWvA HU108 「滑台模组工作台行程接近开关限位感应光电零点开关位置传感器NPN」
 | 天线 | 剑型华硕;SMA内针 | 2 | 5 |  | https://item.taobao.com/item.htm?id=615361930715
 | 显示器 | 14寸 【触摸款 】 Type-C接口/隐形支架/[IPS护眼屏];官方标配[+支架] | 1 | 350 |  | https://item.taobao.com/item.htm?id=994915794027
 | WIFI模块射频连接馈线 | 0.5m;6号内螺内孔外螺内孔174线0-4G线径2.8MM | 2 | 6 |  | https://item.taobao.com/item.htm?id=44863501262 (https://item.taobao.com/item.htm?id=666129032457)
 | L型支架宽 | 黑色78边长-双槽2040-8孔（含欧标螺丝螺母） | 2 | 8 |  | https://item.taobao.com/item.htm?id=627448619941
 | L型支架 | 黑色-单槽2020-2孔（含欧标螺丝螺母） | 2 | 4 |  | https://item.taobao.com/item.htm?id=567240850944
接线部分 | IO扩展板 | RS485;2路;非隔离型;24V | 1 | 32 |  | https://item.taobao.com/item.htm?id=641646267315
 | 电池电量显示器 | 6串锂电[6串锂电电量显示];内装无按键GY-6;白光(white);声光报警款 | 1 | 17 |  | https://item.taobao.com/item.htm?id=524929127650&from=cart&skuId=3921830860539&upStreamPrice=1700
 | 分离模块 | XT30 2+2转GH1.25+XT30 | 4 | 10 |  | https://item.taobao.com/item.htm?id=781570215534
 | USB转CAN MIT驱动器 | 模块【V3.0】+数据线+2pin+3pin套装 | 4 | 65 |  | https://item.taobao.com/item.htm?id=639679565187
 | 降压模块 | 柠檬黄[8-35V转5V3A 母头转Type-c] | 1 | 16 |  | https://item.taobao.com/item.htm?id=522031626999
 |  | 17-55V转12V6A | 1 | 18 |  | https://item.taobao.com/item.htm?id=728638915097
 | 换电源模块 | 默认 | 1 | 88 |  | https://item.taobao.com/item.htm?id=859985772657
 | USB延长线 | 0.6m;【升级款】USB3.0公对母带耳朵【蓝色】 | 2 | 12 |  | https://item.taobao.com/item.htm?id=552349663785
 | 拓展坞 | 【铝合金款】USB扩展USB3.0×4+Type-C供电 | 4 | 37 |  | https://item.taobao.com/item.htm?id=662780224557
 | 拓展坞 | [铝合金1.5米加长线】USB扩展USB3.0x4+Type-C供电 | 2 | 50 |  | https://item.taobao.com/item.htm?id=662780224557
 | 急停开关 | M3铝氧化头部-红色;自锁式（保持式）;带灯9-24V;1NO1NC | 1 | 45 |  | https://item.taobao.com/item.htm?id=658648726917&from=cart&skuId=4925834991211&upStreamPrice=4210
 | 绿按钮开关 | 颜色分类绿色电源灯+带线;电压3-24V;自锁-按下通电-再按断；25MM【20A】 | 1 | 19 |  | https://item.taobao.com/item.htm?id=709235914675&from=cart&skuId=5149779067604&upStreamPrice=1310
 | 红按钮开关 | 颜色分类红色电源灯+带线;电压3-24V;自锁-按下通电-再按断；25MM【20A】 | 1 | 19 |  | https://item.taobao.com/item.htm?id=709235914675&from=cart&skuId=5149779067604&upStreamPrice=1310
 | 网线延长线 | 黑色（公对母）0.6mm | 1 | 6 |  | https://item.taobao.com/item.htm?id=41107441353&from=cart&skuId=3101315285673&upStreamPrice=528
 | 4路8路RS485集线器 | 【USB转RS485模块】 价格11元的那款 | 1 | 11 |  | https://item.taobao.com/item.htm?id=729212927080
 | 限位开关 | 贝尔美SN04-NKB黑色款 | 2 | 6 |  | https://item.taobao.com/item.htm?id=547233352646&from=cart&skuId=4995699381661&upStreamPrice=600
 | 电源防水连接器 | LP24-2(公插+法兰母座) | 2 | 46.5 |  | https://item.taobao.com/item.htm?id=828564042177&from=cart&skuId=5726239234374&upStreamPrice=4650
 | 双公头USB | 2m;【镀金】USB3.0公对公线 | 2 | 14 |  | https://item.taobao.com/item.htm?id=708365168245
 | 英伟达Jetson Orin NX Super开发套件Linux主板AI核心模组nano | 官方Jetson Orin Nano 8G Super 256G硬盘开发套件 | 1 | 3799 |  | https://e.tb.cn/h.8eCF5n39KLI7qyH?tk=bi5Ggwmo19A CZ009 「Jetson Orin Nano Super 8G官方开发套件Orin Nano模组AI视觉识别」
 | 英伟达Jetson Orin Nano/Xavier NX亚克力外壳 | 亚克力外壳 | 1 | 28 |  | https://e.tb.cn/h.83zni5yphOhVe7o?tk=oic5gwmkwo8 CZ057 「英伟达Jetson Orin Nano/Xavier NX亚克力外壳TX2开发板机箱SUPER」
 | 显示屏转接器dp转hdmi线 | dp转hdmi线；1.5m | 1 | 20 |  | https://e.tb.cn/h.8fi0I8siTy4MSzV?tk=D4gLgwmOMKQ HU006 「亚博智能jetson转接器dp转hdmi线4K高清显示屏连接口orin nano/nx」
 | 坦克链导轨 | 15*30 | 1 | 10 |  | https://e.tb.cn/h.8eBCEHZfWQXdh0i?tk=5Li2gwnr1li HU591 「塑料尼龙钢制铝拖链坦克链条线槽桥式全封闭电缆高速静音工程机床」
 | 电源充电口母座 | 2条-DC5.5*2.1mm带线母座+防尘塞-20cm | 1 | 14 |  | https://e.tb.cn/h.8vlSE0NWPSHizU3?tk=JZQOTkC0Eq1 HU926 「DC099带线5.5*2.1/2.5mm母座焊接电源插座大电流金属公母头12V24V」
 | DC5.5*2.1mm带线母座 | 2条-DC5.5*2.1mm带线母座+防尘塞-20cm | 2 | 14 |  | https://e.tb.cn/h.8fRyrkeIz7crwfB?tk=iZUzgwn9aed HU071 「DC099带线5.5*2.1/2.5mm母座焊接电源插座大电流金属公母头12V24V」
 | 圆形USB3.0直通插座 | 锌合金-圆形USB3.0直通插座[银色】 | 2 | 17 |  | https://e.tb.cn/h.8eaN9FVYBnaXNZT?tk=3LlogwnOrHG HU287 「RJ45插座网口网络直通头圆型USB母座超6类机柜钣金连接器网线高清HDMI对接头TYPE-C面板固定接口转接头防尘」
 | 电源线2p-黑红-14awg | 特软硅胶双并线14awg；10米 | 10 | 11 |  | https://e.tb.cn/h.8fisJHajRTb0UAt?tk=Xl5YgwNfycZ MF937 「特软硅胶双并线 30-8AWG连接电线排线 耐高温硅胶红黑双并线」
 | 五色盒装DIY航模导线 | 22AWG(红黑黄蓝绿)5卷共50米/盒 | 1 | 55 |  | https://e.tb.cn/h.8VABxxxWJciux0u?tk=xy30gwNUZ7y HU006 「特软耐高温硅胶线镀锡铜电线软线18 24 30AWG五色盒装DIY航模导线」
 | 快速接线端子 | 二进二出带孔10只 | 2 | 5 |  | https://e.tb.cn/h.8fRlzfId1nzLsZd?tk=ydTXgwn1ing tG-#22>lD 「接线端子接线神器电线快速连接器快接头多功能对接对插接头按压式」
 |  | 二进八出带孔10只 | 1 | 32 |  | https://e.tb.cn/h.8fRlzfId1nzLsZd?tk=ydTXgwn1ing tG-#22>lD 「接线端子接线神器电线快速连接器快接头多功能对接对插接头按压式」
 | 电源插头 | 黑刀片3芯母头 | 1 | 6 |  | https://item.taobao.com/item.htm?id=948071912183
 |  | 黑3芯公头 | 1 | 6 |  | https://item.taobao.com/item.htm?id=948071912183
 | 免焊接DC电源插座5.5*2.1/2.5MM按压式插头公头母头12V | 5.5*2.5公头 1份5只 | 2 | 3 |  | https://item.taobao.com/item.htm?id=619626584933
 |  | 5.5*2.5母头 1份5只 | 2 | 3 |  | https://item.taobao.com/item.htm?id=619626584933
外接设备 | 摄像头 | 130度无畸变（3mm）-200万 | 3 | 208 |  | https://e.tb.cn/h.RG8GR4TqjMhqLTS?tk=GMoTg9QZNuz CZ193 「1080p摄像头高清宽动态广角无畸变高帧率树莓派电脑安卓USB免驱」 点击链接直接打开 或者 淘宝搜索直接打开
 | VR | 新品Quest 3S 128G原装拆封代激活送link线（联系老板：打开开发者模式） | 1 | 2600 |  | https://item.taobao.com/item.htm?id=791726688046
 | 24V电源 | LRS-800-24【24V33.3A】 | 1 | 180 |  | https://e.tb.cn/h.8eBX815GT1MNCDF?tk=GiXygwNENFK CZ001 「明伟LRS-1000W1200W800开关电源集中供电220V转24V48伏直流变压器」
 |  | 国标1.5平方 | 1 | 23 |  | https://e.tb.cn/h.84aoco7tFLIk6Tz?tk=dDc2gwNDrnP CZ057 「国标纯铜电源线三芯0.75平方1.5米开关电源交流输入线350W500专用」
 | 锂电池 | 24V【足容27000mAh】九并六串 | 1 | 486 |  | 【淘宝】https://e.tb.cn/h.RGjiAu6lB5a378z?tk=4wDhg9Qo9ce CZ057 「24V锂电池组6串18650大容量25.2伏电瓶监控灯可充电户外电源电机」 点击链接直接打开 或者 淘宝搜索直接打开
 | 锂电池充电器 | 25.2V 5A充电器 | 1 | 53 |  | 【淘宝】https://e.tb.cn/h.RGjiAu6lB5a378z?tk=4wDhg9Qo9ce CZ057 「24V锂电池组6串18650大容量25.2伏电瓶监控灯可充电户外电源电机」 点击链接直接打开 或者 淘宝搜索直接打开
钣金加工 | CNC | 铨州制造（黑狗木定期会开车，可以上车拼车） | 1套 | 200 | 200 | https://gy2025.com/#/my
 | 钣金件 | 嘉立创 （黑狗木定期会开车，可以上车拼车） | 1套 | 2100 | 2100 | https://www.jlc-bj.com/order/#/placeOrder
 | seeed rebot-DM | 达妙版本机械臂 | 2 | 7400 | 14800 | https://detail.tmall.com/item.htm?id=1042412233386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
3D打印件 | 可自行打印
其他零件 | 螺丝 | 304T型欧标20型-M5(10只) | 5 | 6 |  | https://e.tb.cn/h.8uAt3Ud6rzP03KW?tk=i0lETkCs1op HU108 「304不锈钢t型螺母20/30/40/45型欧标国标铝型材滑块螺帽船型锤头」
 |  | M6*10[100个] | 1 | 15 |  | https://e.tb.cn/h.8uAAweuiy30HeC5?tk=oKRpTkya4Vf CZ009 「固万基10.9级黑镍沉头内六角螺栓DIN7991高强度平杯螺丝平头螺钉」
 |  | M3*8[200个] | 1 | 11
 |  | M3*10[200个] | 1 | 12
 |  | M3*12[200个] | 1 | 13
 |  | M3*18[100个] | 1 | 8
 |  | M4*12[100个] | 1 | 7
 |  | M4*14[100个] | 1 | 8
 |  | M4*16[100个] | 1 | 8
 |  | M4*20[100个] | 1 | 9
 |  | M5*12[100个] | 1 | 10
 |  | HM5×12[100只] | 1 | 8 |  | https://e.tb.cn/h.8GGK5QmHsO8PuuU?tk=FfuhTkAt5P9 CZ193 「【U先试用】12.9级杯头内六角螺丝钉圆柱头螺钉高强度内六角螺栓」
 |  | HM4*16[50只] | 2 | 4
 |  | HM4*22[50只] | 1 | 4
 |  | HM4*25[50只] | 1 | 5
 |  | M3x40[50只] | 1 | 4 |  | https://e.tb.cn/h.8FbptPVTVgnAus5?tk=uZkUTkAF3rr HU287 「304不锈钢十字沉头螺丝钉平头螺栓机丝电子小螺钉大全M2M3M4M5M6」
 |  | M4*70[20只] | 1 | 6
 |  | M3*12(100只)黑色 | 1 | 5 |  | https://e.tb.cn/h.8vMbLh2Y5r3U9Vp?tk=FY6jTkABH6n CZ005 「304不锈钢自攻螺丝十字沉头螺丝钉平头自攻丝KA加长木螺钉M3M4M5」
 |  | M3*16(50只)黑色 | 1 | 4
 | 圆柱销 | 4*12 [100支】 | 1 | 12 |  | https://item.taobao.com/item.htm?id=997633219089
其他工具： | 螺丝刀/剪线钳/黑胶带/扎带/纳米胶/热熔胶枪
 |  |  |  | 合计=

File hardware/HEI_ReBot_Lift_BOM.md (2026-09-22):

# HEI ReBot Lift BOM V1.1

本表由 `HEI_ReBot_Lift_BOM.xlsx`（V1.1）生成，方便在 GitHub 直接查看。
Excel 是可编辑源文件；Markdown 中的总价由 LibreOffice 重新计算公式后导出。

> 价格与采购链接仅作为整理时的参考，可能随时间变化或失效。采购前请重新核对规格、数量、兼容性和实时价格。

| 类别 | 材料名称 | 型号 | 所需数量 | 单价 | 总价 | 采购链接 |
| --- | --- | --- | --- | --- | --- | --- |
| 底盘部分 | 全向轮 | 【Omni B152】直径152mm全向轮*1个（含孔径6mm工业级抱紧式联轴器） | 4 | 229 | 916 | https://item.taobao.com/item.htm?id=692637585058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 |
|  | 轴承 | 6907（35*55*10） | 4 | 6 | 24 | https://item.taobao.com/item.htm?id=724149127063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 |
|  | 无刷电机 | DM-J4310-2ECV1.2 | 5 | 599 | 2995 | https://item.taobao.com/item.htm?id=815333472865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 |
|  | 铝型材 | 100mm 两端攻丝M6欧标2020亮光氧化黑，臂厚1.5 | 10 | 3 | 30 | https://item.taobao.com/item.htm?id=17388859879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 |
|  | XT30单头线 | XT30U黄母V2版，14AWG(2.07平方)红黑线; 20cm | 3 | 9 | 27 | https://e.tb.cn/h.84Y2Y6OhkDc8Qd8?tk=0uragDI49y7 CZ193 「络黎XT30单头线XT30U转接线充电线带线插头延长线硅胶线特软软线」 |
|  | XT30单头线 | XT30U黄母V2版，14AWG(2.07平方)红黑线; 50cm | 1 | 12 | 12 | https://e.tb.cn/h.84Y2Y6OhkDc8Qd8?tk=0uragDI49y7 CZ193 「络黎XT30单头线XT30U转接线充电线带线插头延长线硅胶线特软软线」 |
|  | 电机连接线 | XT30(2+2)-F30厘米双母头延长线 | 6 | 15 | 90 | https://item.taobao.com/item.htm?id=822600109037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 |
|  | 电机连接线 | XT30(2+2)双母头35厘米正弯+直头 | 4 | 15 | 60 | https://item.taobao.com/item.htm?id=822600109037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 |
| 升降部分 | 滑台模组GX | 1610丝杆800mm（找客服即可） | 1 | 429 | 429 | https://e.tb.cn/h.8exLaJE0rK9YDGT?tk=W1smgwOj0wZ CZ005 「含增票GX80双导轨直线滚珠丝杆滑台模组含57电机铝合金十字工作台」 |
|  | 接近开关支架 | 单独支架 | 2 | 1 | 2 | https://e.tb.cn/h.8tJ2jyyiOJci8S7?tk=nQa7TkDqWvA HU108 「滑台模组工作台行程接近开关限位感应光电零点开关位置传感器NPN」 |
|  | 天线 | 剑型华硕;SMA内针 | 2 | 5 | 10 | https://item.taobao.com/item.htm?id=615361930715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 |
|  | 显示器 | 14寸 【触摸款 】 Type-C接口/隐形支架/[IPS护眼屏];官方标配[+支架] | 1 | 350 | 350 | https://item.taobao.com/item.htm?id=994915794027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 |
|  | WIFI模块射频连接馈线 | 0.5m;6号内螺内孔外螺内孔174线0-4G线径2.8MM | 2 | 6 | 12 | https://item.taobao.com/item.htm?id=44863501262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 |
|  | L型支架宽 | 黑色78边长-双槽2040-8孔（含欧标螺丝螺母） | 2 | 8 | 16 | https://item.taobao.com/item.htm?id=627448619941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 |
|  | L型支架 | 黑色-单槽2020-2孔（含欧标螺丝螺母） | 2 | 4 | 8 | https://item.taobao.com/item.htm?id=567240850944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 |
| 接线部分 | IO扩展板 | RS485;2路;非隔离型;24V | 1 | 32 | 32 | https://item.taobao.com/item.htm?id=641646267315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 |
|  | 电池电量显示器 | 6串锂电[6串锂电电量显示];内装无按键GY-6;白光(white);声光报警款 | 1 | 17 | 17 | https://item.taobao.com/item.htm?id=524929127650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 |
|  | 分离模块 | XT30 2+2转GH1.25+XT30 | 4 | 10 | 40 | https://item.taobao.com/item.htm?id=781570215534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 |
|  | USB转CAN MIT驱动器 | 模块【V3.0】+数据线+2pin+3pin套装 | 4 | 65 | 260 | https://item.taobao.com/item.htm?id=639679565187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 |
|  | 降压模块 | 柠檬黄[8-35V转5V3A 母头转Type-c] | 1 | 16 | 16 | https://item.taobao.com/item.htm?id=522031626999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 |
|  |  | 17-55V转12V6A | 1 | 18 | 18 | https://item.taobao.com/item.htm?id=728638915097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 |
|  | 换电源模块 | 默认 | 1 | 88 | 88 | https://item.taobao.com/item.htm?id=859985772657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 |
|  | USB延长线 | 0.6m;【升级款】USB3.0公对母带耳朵【蓝色】 | 2 | 12 | 24 | https://item.taobao.com/item.htm?id=552349663785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 |
|  | 拓展坞 | 【铝合金款】USB扩展USB3.0×4+Type-C供电 | 4 | 37 | 148 | https://item.taobao.com/item.htm?id=662780224557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 |
|  | 拓展坞 | [铝合金1.5米加长线】USB扩展USB3.0x4+Type-C供电 | 2 | 50 | 100 | https://item.taobao.com/item.htm?id=662780224557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 |
|  | 急停开关 | M3铝氧化头部-红色;自锁式（保持式）;带灯9-24V;1NO1NC | 1 | 45 | 45 | https://item.taobao.com/item.htm?id=658648726917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 |
|  | 绿按钮开关 | 颜色分类绿色电源灯+带线;电压3-24V;自锁-按下通电-再按断；25MM【20A】 | 1 | 19 | 19 | https://item.taobao.com/item.htm?id=709235914675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 |
|  | 红按钮开关 | 颜色分类红色电源灯+带线;电压3-24V;自锁-按下通电-再按断；25MM【20A】 | 1 | 19 | 19 | https://item.taobao.com/item.htm?id=709235914675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 |
|  | 网线延长线 | 黑色（公对母）0.6mm | 1 | 6 | 6 | https://item.taobao.com/item.htm?id=41107441353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 |
|  | 4路8路RS485集线器 | 【USB转RS485模块】  价格11元的那款 | 1 | 11 | 11 | https://item.taobao.com/item.htm?id=729212927080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 |
|  | 限位开关 | 贝尔美SN04-NKB黑色款 | 2 | 6 | 12 | https://item.taobao.com/item.htm?id=547233352646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 |
|  | 电源防水连接器 | LP24-2(公插+法兰母座) | 2 | 46.5 | 93 | https://item.taobao.com/item.htm?id=828564042177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 |
|  | 双公头USB | 2m;【镀金】USB3.0公对公线 | 2 | 14 | 28 | https://item.taobao.com/item.htm?id=708365168245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 |
|  | 英伟达Jetson Orin NX Super开发套件Linux主板AI核心模组nano | 官方Jetson Orin Nano 8G Super 256G硬盘开发套件 | 1 | 3799 | 3799 | https://e.tb.cn/h.8eCF5n39KLI7qyH?tk=bi5Ggwmo19A CZ009 「Jetson Orin Nano Super 8G官方开发套件Orin Nano模组AI视觉识别」 |
|  | 英伟达Jetson Orin Nano/Xavier NX亚克力外壳 | 亚克力外壳 | 1 | 28 | 28 | https://e.tb.cn/h.83zni5yphOhVe7o?tk=oic5gwmkwo8 CZ057 「英伟达Jetson Orin Nano/Xavier NX亚克力外壳TX2开发板机箱SUPER」 |
|  | 显示屏转接器dp转hdmi线 | dp转hdmi线；1.5m | 1 | 20 | 20 | https://e.tb.cn/h.8fi0I8siTy4MSzV?tk=D4gLgwmOMKQ HU006 「亚博智能jetson转接器dp转hdmi线4K高清显示屏连接口orin nano/nx」 |
|  | 坦克链导轨 | 15*30 | 1 | 10 | 10 | https://e.tb.cn/h.8eBCEHZfWQXdh0i?tk=5Li2gwnr1li HU591 「塑料尼龙钢制铝拖链坦克链条线槽桥式全封闭电缆高速静音工程机床」 |
|  | 电源充电口母座 | 2条-DC5.5*2.1mm带线母座+防尘塞-20cm | 1 | 14 | 14 | https://e.tb.cn/h.8vlSE0NWPSHizU3?tk=JZQOTkC0Eq1 HU926 「DC099带线5.5*2.1/2.5mm母座焊接电源插座大电流金属公母头12V24V」 |
|  | DC5.5*2.1mm带线母座 | 2条-DC5.5*2.1mm带线母座+防尘塞-20cm | 2 | 14 | 28 | https://e.tb.cn/h.8fRyrkeIz7crwfB?tk=iZUzgwn9aed HU071 「DC099带线5.5*2.1/2.5mm母座焊接电源插座大电流金属公母头12V24V」 |
|  | 圆形USB3.0直通插座 | 锌合金-圆形USB3.0直通插座[银色】 | 2 | 17 | 34 | https://e.tb.cn/h.8eaN9FVYBnaXNZT?tk=3LlogwnOrHG HU287 「RJ45插座网口网络直通头圆型USB母座超6类机柜钣金连接器网线高清HDMI对接头TYPE-C面板固定接口转接头防尘」 |
|  | 电源线2p-黑红-14awg | 特软硅胶双并线14awg；10米 | 10 | 11 | 110 | https://e.tb.cn/h.8fisJHajRTb0UAt?tk=Xl5YgwNfycZ MF937 「特软硅胶双并线 30-8AWG连接电线排线 耐高温硅胶红黑双并线」 |
|  | 五色盒装DIY航模导线 | 22AWG(红黑黄蓝绿)5卷共50米/盒 | 1 | 55 | 55 | https://e.tb.cn/h.8VABxxxWJciux0u?tk=xy30gwNUZ7y HU006 「特软耐高温硅胶线镀锡铜电线软线18 24 30AWG五色盒装DIY航模导线」 |
|  | 快速接线端子 | 二进二出带孔10只 | 2 | 5 | 10 | https://e.tb.cn/h.8fRlzfId1nzLsZd?tk=ydTXgwn1ing tG-#22>lD 「接线端子接线神器电线快速连接器快接头多功能对接对插接头按压式」 |
|  |  | 二进八出带孔10只 | 1 | 32 | 32 | https://e.tb.cn/h.8fRlzfId1nzLsZd?tk=ydTXgwn1ing tG-#22>lD 「接线端子接线神器电线快速连接器快接头多功能对接对插接头按压式」 |
|  | 电源插头 | 黑刀片3芯母头 | 1 | 6 | 6 | https://item.taobao.com/item.htm?id=948071912183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 |
|  |  | 黑3芯公头 | 1 | 6 | 6 | https://item.taobao.com/item.htm?id=948071912183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 |
|  | 免焊接DC电源插座5.5*2.1/2.5MM按压式插头公头母头12V | 5.5*2.5公头 1份5只 | 2 | 3 | 6 | https://item.taobao.com/item.htm?id=619626584933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 |
|  |  | 5.5*2.5母头 1份5只 | 2 | 3 | 6 | https://item.taobao.com/item.htm?id=619626584933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 |
| 外接设备 | 摄像头 | 130度无畸变（3mm）-200万 | 3 | 208 | 624 | https://e.tb.cn/h.RG8GR4TqjMhqLTS?tk=GMoTg9QZNuz CZ193 「1080p摄像头高清宽动态广角无畸变高帧率树莓派电脑安卓USB免驱」 点击链接直接打开 或者 淘宝搜索直接打开 |
|  | VR | 新品Quest 3S 128G原装拆封代激活送link线（联系老板：打开开发者模式） | 1 | 2600 | 2600 | https://item.taobao.com/item.htm?id=791726688046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 |
|  | 24V电源 | LRS-800-24【24V33.3A】 | 1 | 180 | 180 | https://e.tb.cn/h.8eBX815GT1MNCDF?tk=GiXygwNENFK CZ001 「明伟LRS-1000W1200W800开关电源集中供电220V转24V48伏直流变压器」 |
|  |  | 国标1.5平方 | 1 | 23 | 23 | https://e.tb.cn/h.84aoco7tFLIk6Tz?tk=dDc2gwNDrnP CZ057 「国标纯铜电源线三芯0.75平方1.5米开关电源交流输入线350W500专用」 |
|  | 锂电池 | 24V【足容27000mAh】九并六串 | 1 | 486 | 486 | 【淘宝】https://e.tb.cn/h.RGjiAu6lB5a378z?tk=4wDhg9Qo9ce CZ057 「24V锂电池组6串18650大容量25.2伏电瓶监控灯可充电户外电源电机」 点击链接直接打开 或者 淘宝搜索直接打开 |
|  | 锂电池充电器 | 25.2V 5A充电器 | 1 | 53 | 53 | 【淘宝】https://e.tb.cn/h.RGjiAu6lB5a378z?tk=4wDhg9Qo9ce CZ057 「24V锂电池组6串18650大容量25.2伏电瓶监控灯可充电户外电源电机」 点击链接直接打开 或者 淘宝搜索直接打开 |
| 钣金加工 | CNC | 铨州制造（黑狗木定期会开车，可以上车拼车） | 1套 | 200 | 200 | https://gy2025.com/#/my |
|  | 钣金件 | 嘉立创  （黑狗木定期会开车，可以上车拼车） | 1套 | 2100 | 2100 | https://www.jlc-bj.com/order/#/placeOrder |
|  | seeed rebot-DM | 达妙版本机械臂 | 2 | 7400 | 14800 | https://detail.tmall.com/item.htm?id=1042412233386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 |
| 3D打印件 | 可自行打印 |  |  |  |  |  |
| 其他零件 | 螺丝 | 304T型欧标20型-M5(10只) | 5 | 6 | 30 | https://e.tb.cn/h.8uAt3Ud6rzP03KW?tk=i0lETkCs1op HU108 「304不锈钢t型螺母20/30/40/45型欧标国标铝型材滑块螺帽船型锤头」 |
|  |  | M6*10[100个] | 1 | 15 | 15 | https://e.tb.cn/h.8uAAweuiy30HeC5?tk=oKRpTkya4Vf CZ009 「固万基10.9级黑镍沉头内六角螺栓DIN7991高强度平杯螺丝平头螺钉」 |
|  |  | M3*8[200个] | 1 | 11 | 11 |  |
|  |  | M3*10[200个] | 1 | 12 | 12 |  |
|  |  | M3*12[200个] | 1 | 13 | 13 |  |
|  |  | M3*18[100个] | 1 | 8 | 8 |  |
|  |  | M4*12[100个] | 1 | 7 | 7 |  |
|  |  | M4*14[100个] | 1 | 8 | 8 |  |
|  |  | M4*16[100个] | 1 | 8 | 8 |  |
|  |  | M4*20[100个] | 1 | 9 | 9 |  |
|  |  | M5*12[100个] | 1 | 10 | 10 |  |
|  |  | HM5×12[100只] | 1 | 8 | 8 | https://e.tb.cn/h.8GGK5QmHsO8PuuU?tk=FfuhTkAt5P9 CZ193 「【U先试用】12.9级杯头内六角螺丝钉圆柱头螺钉高强度内六角螺栓」 |
|  |  | HM4*16[50只] | 2 | 4 | 8 |  |
|  |  | HM4*22[50只] | 1 | 4 | 4 |  |
|  |  | HM4*25[50只] | 1 | 5 | 5 |  |
|  |  | M3x40[50只] | 1 | 4 | 4 | https://e.tb.cn/h.8FbptPVTVgnAus5?tk=uZkUTkAF3rr HU287 「304不锈钢十字沉头螺丝钉平头螺栓机丝电子小螺钉大全M2M3M4M5M6」 |
|  |  | M4*70[20只] | 1 | 6 | 6 |  |
|  |  | M3*12(100只)黑色 | 1 | 5 | 5 | https://e.tb.cn/h.8vMbLh2Y5r3U9Vp?tk=FY6jTkABH6n CZ005 「304不锈钢自攻螺丝十字沉头螺丝钉平头自攻丝KA加长木螺钉M3M4M5」 |
|  |  | M3*16(50只)黑色 | 1 | 4 | 4 |  |
|  | 圆柱销 | 4*12 [100支】 | 1 | 12 | 12 | https://item.taobao.com/item.htm?id=997633219089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 |
| 其他工具： | 螺丝刀/剪线钳/黑胶带/扎带/纳米胶/热熔胶枪 |  |  |  |  |  |
|  |  |  |  | 合计= | 31374 |  |

## 版本信息

- BOM 版本：V1.1
- 项目文件名：`HEI_ReBot_Lift_BOM.xlsx`
- 表内合计：31374 元
- 非空内容行：80（包含工具说明和合计行）

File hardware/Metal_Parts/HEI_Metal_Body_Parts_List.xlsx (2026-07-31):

序号 | 零件名称 | 数量 | 材质 | 是否攻丝 | 是否焊接 | 表面处理 | 备注
1 | part danpan_dm_zhijia.STEP | 4 | 不锈钢-201 | 需要 | 不需要 | 喷塑哑黑
2 | part dipan_1.STEP | 2 | 不锈钢-201 | 需要 | 不需要 | 喷塑哑黑 | 要求钢材平整，不能有弧度
3 | part shengjiang_falan_zhijia.STEP | 1 | 铝合金-5052 | 不需要 | 不需要 | 喷塑哑黑
4 | part waike 2.STEP | 1 | 铝合金-5052 | 不需要 | 需要 | 喷塑哑黑 | 改成3mm厚了
5 | part waike 3.STEP | 1 | 铝合金-5052 | 需要 | 不需要 | 喷塑哑黑
6 | part waike 5.STEP | 1 | 铝合金-5052 | 需要 | 不需要 | 喷塑哑黑
7 | part yaobu_1.STEP | 1 | 不锈钢-201 | 需要 | 不需要 | 喷塑哑黑
8 | part yaobu_2.STEP | 1 | 不锈钢-201 | 需要 | 不需要 | 喷塑哑黑
9 | part yaobu_3.STEP | 1 | 铝合金-5052 | 不需要 | 需要 | 喷塑哑黑 | 改成3mm厚了
以下需要cnc
1 | cnc-DM_4340P_banjin_falan.STEP | 4 | 铝合金
2 | cnc-part_shengjiang_falan.STEP | 1 | 铝合金

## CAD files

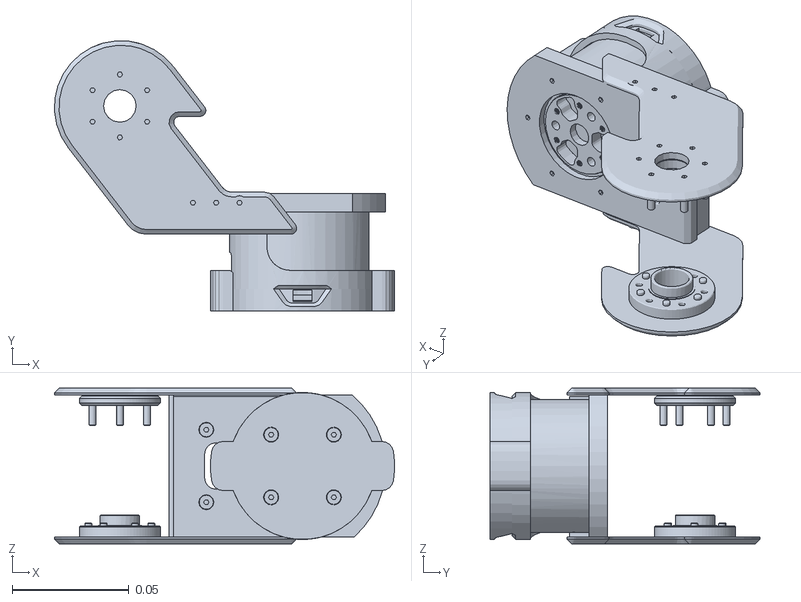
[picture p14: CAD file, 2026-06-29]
examples/hei_rebot_lift/VR_mujoco_ik/mujoco_ik/model/reBot_description/meshes/link4.STL
0.146 x 0.116 x 0.0668

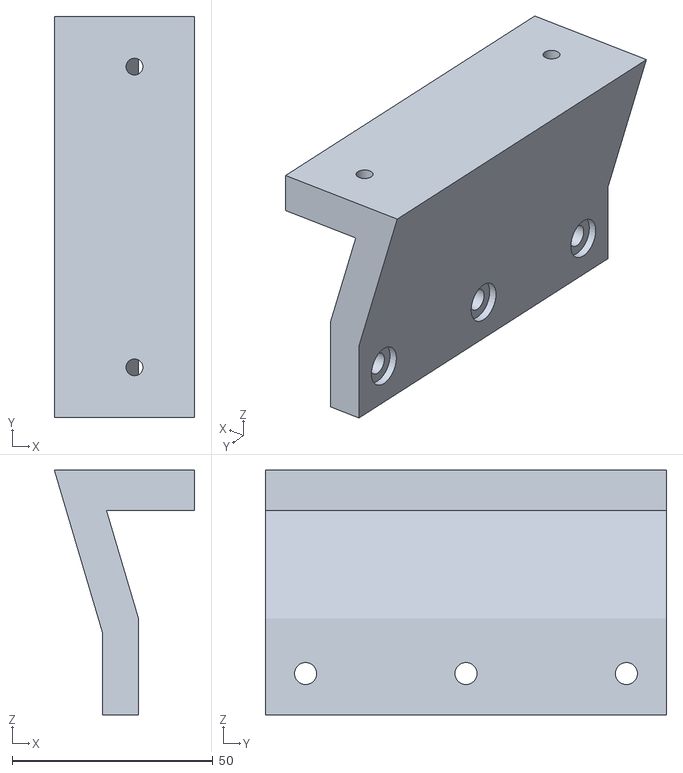
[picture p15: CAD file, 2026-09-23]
hardware/3D_Printed_Parts/part_waike_6.STL
35.0 x 100.0 x 61.0

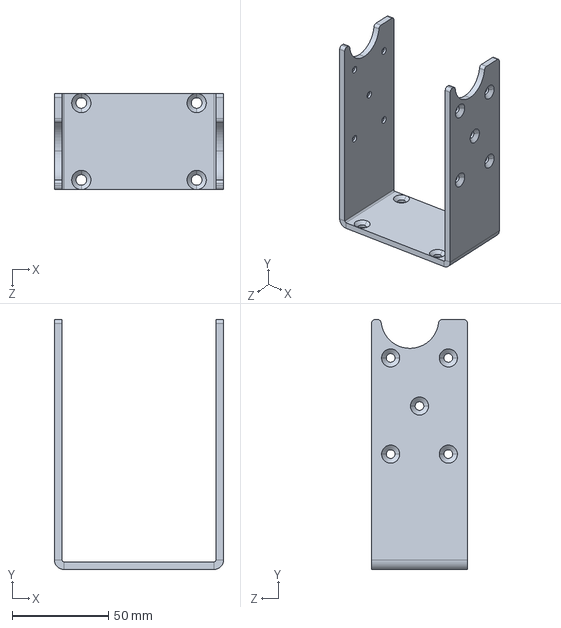
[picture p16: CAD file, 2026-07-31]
hardware/Metal_Parts/step/part_yaobu_1.STEP
88.0 x 130.0 x 50.0 mm

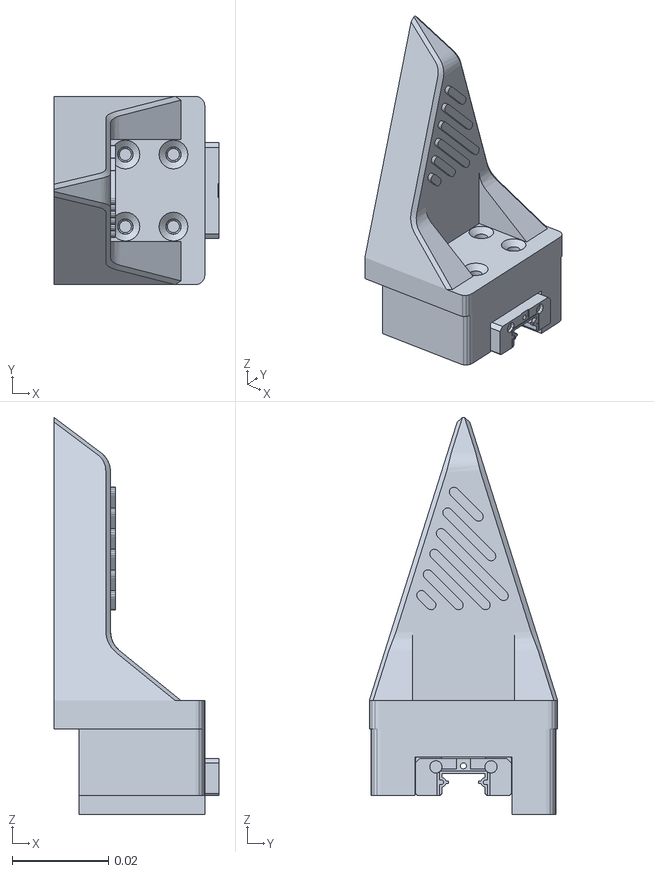
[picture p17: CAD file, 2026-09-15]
software/lerobot-hei-rebot-lift/examples/hei_rebot_lift/VR_mujoco_ik/mujoco_ik/model/HEI_robot_urdf/meshes/b_left_end_link_L_finger.STL
0.0343 x 0.0392 x 0.0826

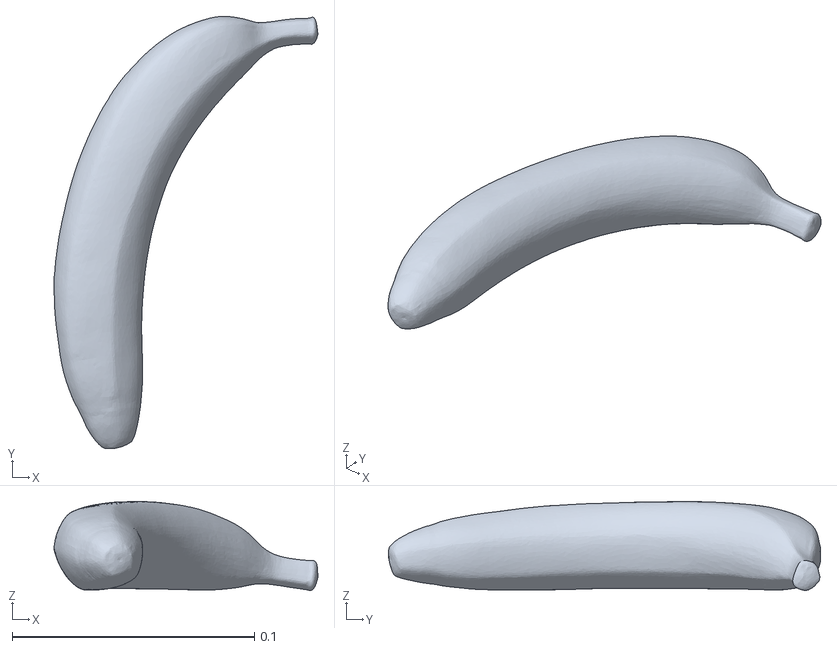
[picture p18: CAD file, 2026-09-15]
software/lerobot-hei-rebot-lift/examples/hei_rebot_lift/VR_mujoco_ik/mujoco_ik/model/HEI_robot_urdf/scene_assets/ycb_011_banana/textured.obj
0.109 x 0.178 x 0.0367

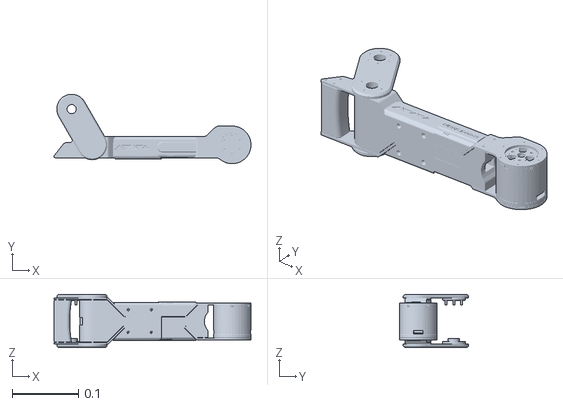
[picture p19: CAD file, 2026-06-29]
examples/hei_rebot_lift/VR_mujoco_ik/mujoco_ik/model/reBot_description/meshes/link3.STL
0.298 x 0.105 x 0.0802

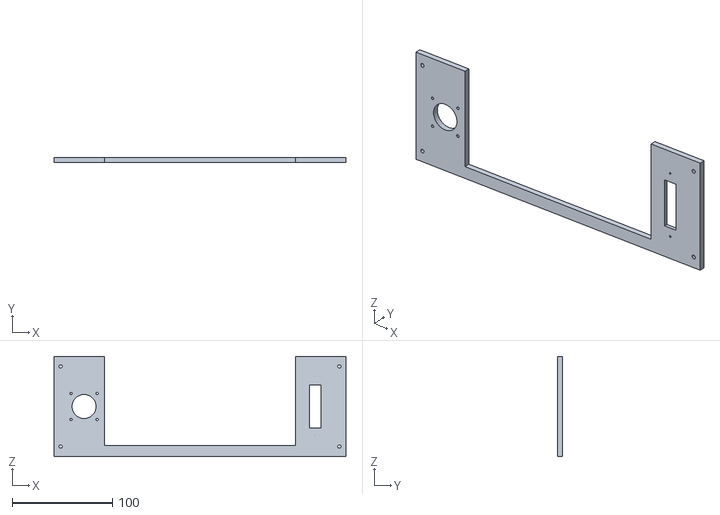
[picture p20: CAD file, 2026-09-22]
hardware/3D_Printed_Parts/part_dipan_3-1.STL
291.6 x 5.00 x 100.0

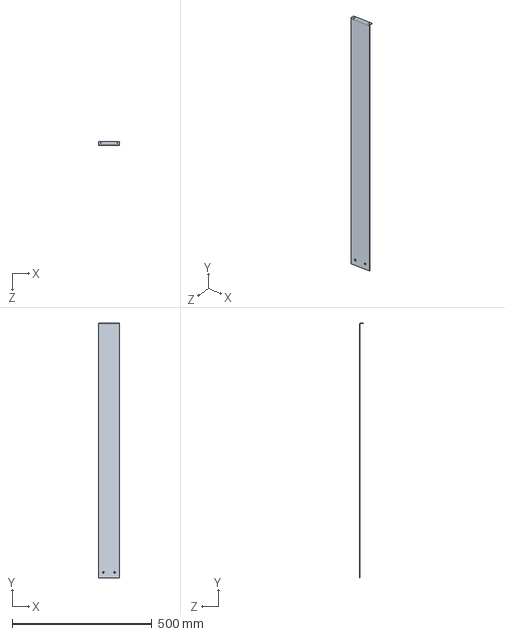
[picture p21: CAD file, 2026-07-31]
hardware/Metal_Parts/step/part_waike_3.STEP
76.0 x 911.0 x 14.0 mm

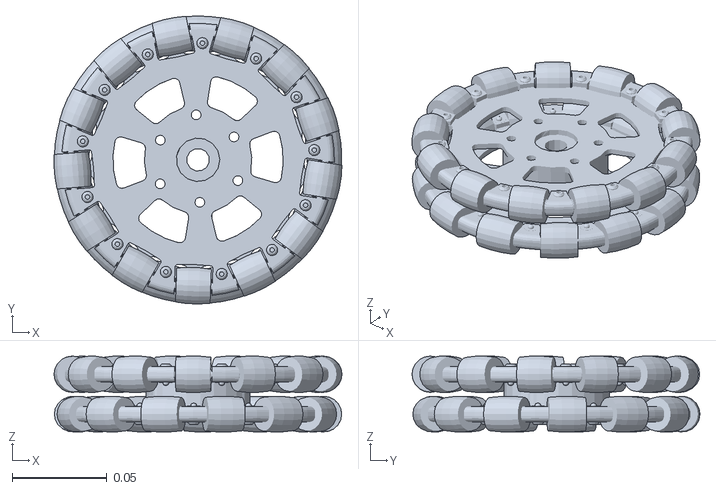
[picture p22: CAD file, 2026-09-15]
software/lerobot-hei-rebot-lift/examples/hei_rebot_lift/VR_mujoco_ik/mujoco_ik/model/HEI_robot_urdf/meshes/front_left_wheel_link.STL
0.152 x 0.152 x 0.0401

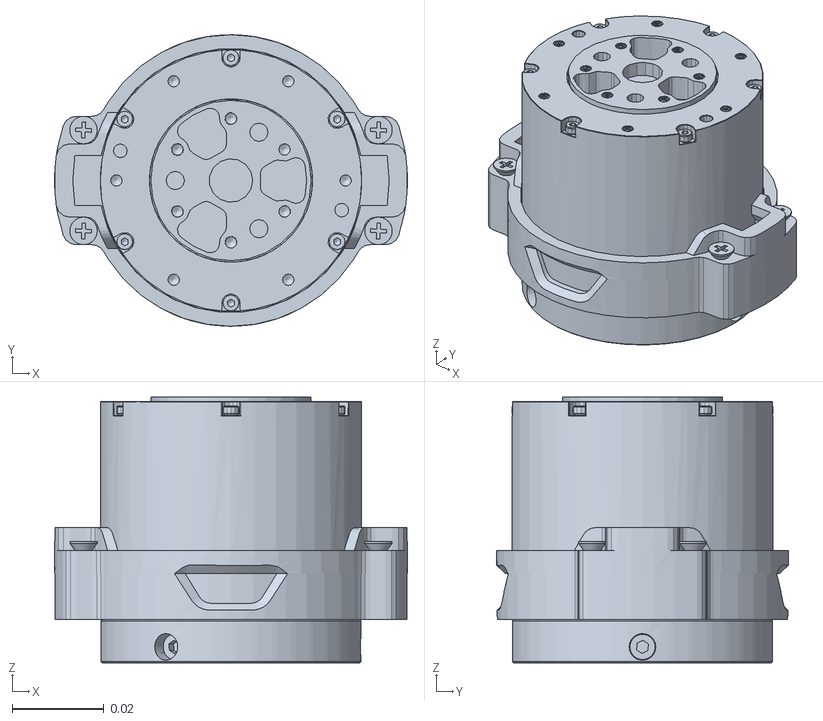
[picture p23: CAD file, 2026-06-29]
examples/hei_rebot_lift/VR_mujoco_ik/mujoco_ik/model/reBot_description/meshes/link6.STL
0.077 x 0.0636 x 0.058

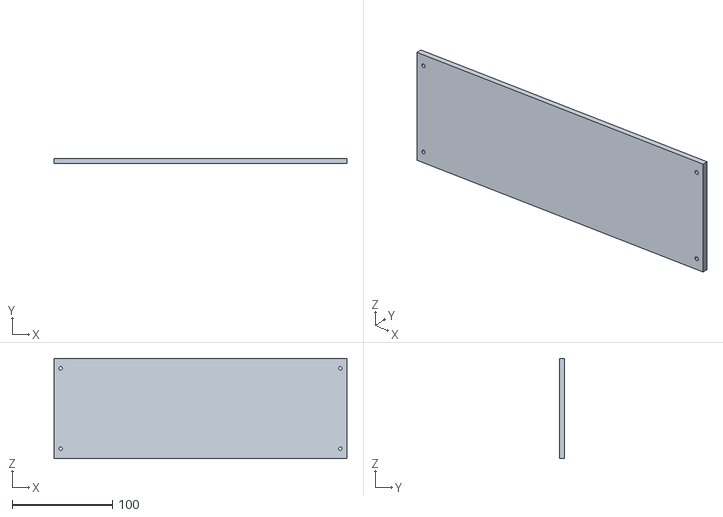
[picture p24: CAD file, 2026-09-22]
hardware/3D_Printed_Parts/part_dipan_3_4.STL
291.6 x 5.00 x 100.0

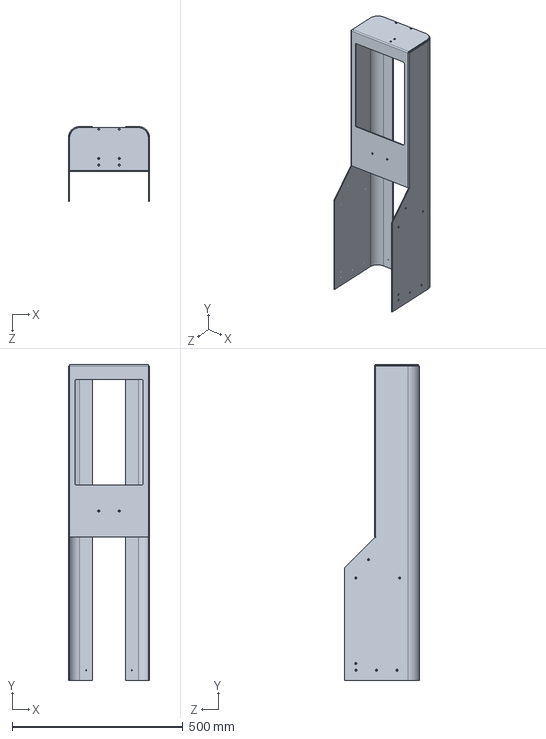
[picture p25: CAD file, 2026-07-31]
hardware/Metal_Parts/step/part_waike_2.STEP
238.0 x 924.0 x 219.0 mm

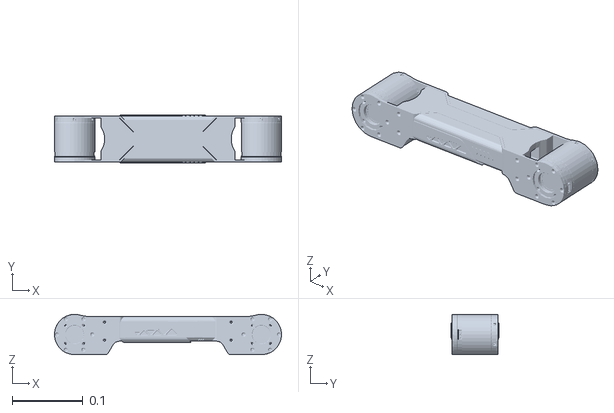
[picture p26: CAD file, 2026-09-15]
software/lerobot-hei-rebot-lift/examples/hei_rebot_lift/VR_mujoco_ik/mujoco_ik/model/HEI_robot_urdf/meshes/a_right_link2.STL
0.321 x 0.0674 x 0.057

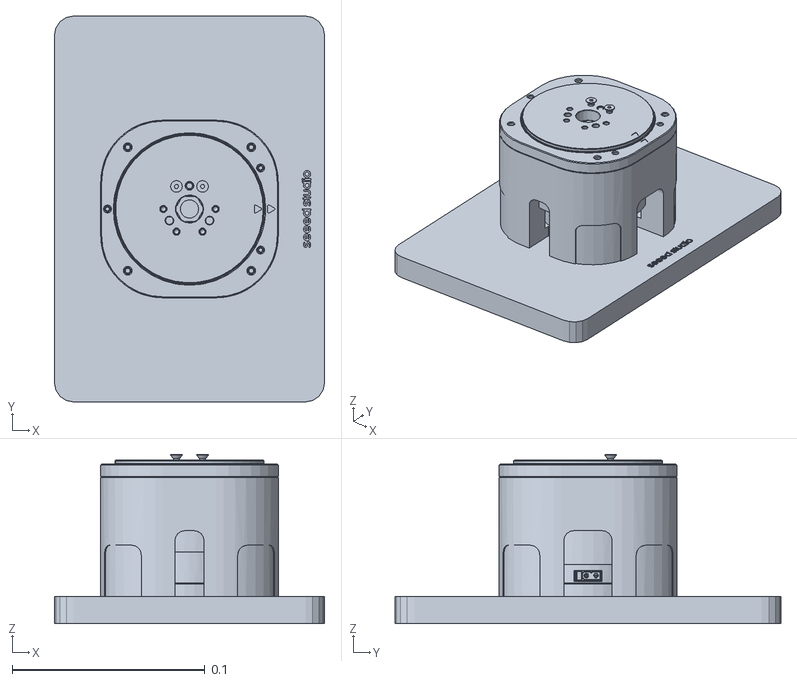
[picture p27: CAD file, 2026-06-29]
examples/hei_rebot_lift/VR_mujoco_ik/mujoco_ik/model/reBot_description/meshes/base_link.STL
0.14 x 0.2 x 0.0877

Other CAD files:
hardware/Metal_Parts/step/part_waike_5.STEP
software/lerobot-hei-rebot-lift/examples/hei_rebot_lift/VR_mujoco_ik/mujoco_ik/model/HEI_robot_urdf/meshes/a_right_base_link.STL
examples/hei_rebot_lift/VR_mujoco_ik/mujoco_ik/model/reBot_description/meshes/link5.STL
examples/hei_rebot_lift/VR_mujoco_ik/mujoco_ik/model/reBot_description/meshes/link1.STL
hardware/3D_Printed_Parts/part_danpan_dm_zhijia_dayin-1.STL
hardware/3D_Printed_Parts/part_danpan_dm_zhijia_dayin-2.STL
hardware/3D_Printed_Parts/part_danpan_dm_zhijia_dayin-3.STL
hardware/3D_Printed_Parts/part_dianchi_ke_1.STL
hardware/3D_Printed_Parts/part_dianchi_ke_2.STL
hardware/3D_Printed_Parts/part_dianchi_ke_3.STL
hardware/3D_Printed_Parts/part_shengjiang_10.STL
hardware/3D_Printed_Parts/part_shengjiang_11.STL
hardware/3D_Printed_Parts/part_shengjiang_12.STL
hardware/3D_Printed_Parts/part_shengjiang_6.STL
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

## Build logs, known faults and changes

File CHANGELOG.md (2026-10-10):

# Changelog

All notable changes to HEI ReBot Lift are documented here. Project releases use
Git tags such as `v0.1.0` and `v0.2.0`. The version in
`software/lerobot-hei-rebot-lift/pyproject.toml` is the bundled LeRobot package
version and is intentionally managed separately.

## [0.2.0] - 2026-10-10

### Added

- Added an explicit HEI project version in `VERSION` and an upstream baseline
  record in `software/lerobot-hei-rebot-lift/UPSTREAM.md`.
- Added the `hei_rebot_lift` dependency extra and the
  `hei-rebot-lift-host` console entry point.
- Added compatibility decoding for both the new multipart observation protocol
  and the legacy Base64 JSON protocol.

### Changed

- Synchronized the software foundation with LeRobot `0.6.2`, upstream commit
  `b9cb121cb7d4e3e26ec5c906d08dda68d151ba52`.
- Migrated HEI recording, evaluation, robot registration, policy processing,
  datasets, training, and rollout integrations to the latest LeRobot APIs.
- Changed Host camera transport to a compact JSON state header followed by raw
  JPEG frames, reducing CPU and network overhead.
- Updated `lerobot-find-cameras` to use MJPG `640x480@30` by default and verify
  multiple OpenCV cameras concurrently.
- Updated English, Chinese, French, and Spanish deployment documentation.
- Replaced obsolete generated requirements files with dependency definitions in
  `pyproject.toml`.

### Compatibility

- Preserves the 18-dimensional HEI state/action layout.
- Preserves the `front`, `left_wrist`, and `right_wrist` camera feature names.
- Existing MuJoCo datasets and ACT checkpoints remain loadable.

## [0.1.0] - 2026-10-09

- First public HEI ReBot Lift baseline.
- Includes the dual-arm robot driver, lift and omnidirectional chassis control,
  VR/MuJoCo IK workflows, keyboard simulation, data recording, ACT/VLA examples,
  hardware BOM, CAD/STEP resources, wiring notes, and deployment guides.

[0.2.0]: https://github.com/lipengdong/hei-rebot-lift/compare/v0.1.0...v0.2.0
[0.1.0]: https://github.com/lipengdong/hei-rebot-lift/releases/tag/v0.1.0

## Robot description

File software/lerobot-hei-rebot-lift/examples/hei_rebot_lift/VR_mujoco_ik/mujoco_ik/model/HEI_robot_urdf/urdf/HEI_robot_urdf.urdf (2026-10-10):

<?xml version="1.0" encoding="utf-8"?>
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
<robot name="HEI_robot_urdf">
  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
  <mujoco>
    <compiler meshdir="../meshes" strippath="true" discardvisual="false" fusestatic="false" balanceinertia="false" />
  </mujoco>
  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
  <link name="base_footprint" />
  <joint name="base_footprint_joint" type="fixed">
    <origin xyz="0.0577141065 0.0318598182 -0.0427861037" rpy="0 0 -1.5707963268" />
    <parent link="base_footprint" />
    <child link="base_link" />
  </joint>
  <link name="base_link">
    <inertial>
      <origin xyz="0.0318500736747143 0.134408250107984 0.0750627469843922" rpy="0 0 0" />
      <mass value="4.4369989053719" />
      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
    </inertial>
    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
  </link>
  <link name="front_left_wheel_link">
    <inertial>
      <origin xyz="-3.40416028699053E-11 -1.2340328758853E-10 0.00558469119775667" rpy="0 0 0" />
      <mass value="0.00163612324488368" />
      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
    </inertial>
    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
  </link>
  <joint name="front_left_wheel_joint" type="continuous">
    <origin xyz="-0.191724182567996 0.165869894313329 0.119" rpy="1.5707963267949 0 -2.35619449019236" />
    <parent link="base_link" />
    <child link="front_left_wheel_link" />
    <axis xyz="0 0 1" />
  </joint>
  <link name="front_right_wheel_link">
    <inertial>
      <origin xyz="-6.06419775506239E-11 1.12732961854434E-10 0.00558469119775862" rpy="0 0 0" />
      <mass value="0.00163612324488367" />
      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
    </inertial>
    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
  </link>
  <joint name="front_right_wheel_joint" type="continuous">
    <origin xyz="0.25544381896979 0.165869894313322 0.118999999999999" rpy="1.5707963267949 0 2.35619449019222" />
    <parent link="base_link" />
    <child link="front_right_wheel_link" />
    <axis xyz="0 0 1" />
  </joint>
  <link name="rear_left_wheel_link">
    <inertial>
      <origin xyz="-6.06427408289534E-11 1.12737277846442E-10 0.00558469119775673" rpy="0 0 0" />
      <mass value="0.00163612324488369" />
      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
    </inertial>
    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
  </link>
  <joint name="rear_left_wheel_joint" type="continuous">
    <origin xyz="-0.191724182567998 -0.281298107224456 0.119000000000001" rpy="1.5707963267949 0 -0.785398163397458" />
    <parent link="base_link" />
    <child link="rear_left_wheel_link" />
    <axis xyz="0 0 1" />
  </joint>
  <link name="rear_right_wheel_link">
    <inertial>
      <origin xyz="-6.06426853178021E-11 1.12736875390596E-10 0.00558469119775673" rpy="0 0 0" />
      <mass value="0.00163612324488366" />
      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
    </inertial>
    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
  </link>
  <joint name="rear_right_wheel_joint" type="continuous">
    <origin xyz="0.25544381896978 -0.281298107224448 0.118999999999994" rpy="1.57079632679489 0 0.785398163397448" />
    <parent link="base_link" />
    <child link="rear_right_wheel_link" />
    <axis xyz="0 0 1" />
  </joint>
  <link name="lidar_link">
    <inertial>
      <origin xyz="-0.00250804290421403 6.44352150802607E-09 0.0171069574143055" rpy="0 0 0" />
      <mass value="0.0374330181560157" />
      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
    </inertial>
    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
  </link>
  <joint name="lidar_joint" type="fixed">
    <origin xyz="0.0318598182009012 0.152285893544438 0.19" rpy="0 0 1.57079632679488" />
    <parent link="base_link" />
    <child link="lidar_link" />
    <axis xyz="0 0 0" />
  </joint>
  <link name="imu_link">
    <inertial>
      <origin xyz="1.64769300436962E-06 1.64769301196077E-06 0.00499999999999999" rpy="0 0 0" />
      <mass value="0.0357486725877128" />
      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
    </inertial>
    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
  </link>
  <joint name="imu_joint" type="fixed">
    <origin xyz="0.0318598182009012 0.152285893544438 0.0850000000000001" rpy="0 0 1.57079632679488" />
    <parent link="base_link" />
    <child link="imu_link" />
    <axis xyz="0 0 0" />
  </joint>
  <link name="lift_column_link">
    <inertial>
      <origin xyz="-0.00435168272787461 0.469610437281469 0.0952387774941474" rpy="0 0 0" />
      <mass value="2.88486740861506" />
      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
    </inertial>
    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
  </link>
  <joint name="lift_column_joint" type="fixed">
    <origin xyz="0.03186 -0.032214 0.19" rpy="1.5708 0 0" />
    <parent link="base_link" />
    <child link="lift_column_link" />
    <axis xyz="0 0 0" />
  </joint>
  <link name="lift_carriage_link">
    <inertial>
      <origin xyz="0.0756204015645276 0.00224613261704043 0.0109761810755997" rpy="0 0 0" />
      <mass value="1.54411126706519" />
      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
    </inertial>
    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
  </link>
  <joint name="lift_joint" type="prismatic">
    <origin xyz="0 0.87 0.0255" rpy="1.5708 1.5708 3.1416" />
    <parent link="lift_column_link" />
    <child link="lift_carriage_link" />
    <axis xyz="0 0 1" />
    <limit lower="-0.7" upper="0" effort="0" velocity="0" />
  </joint>
  <link name="a_right_base_link">
    <inertial>
      <origin xyz="6.56684538122981E-06 -2.07448643286812E-05 0.0349662004906963" rpy="0 0 0" />
      <mass value="0.402787177092637" />
      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
    </inertial>
    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
  </link>
  <joint name="a_right_base_mount" type="fixed">
    <origin xyz="0.096 -0.23 -0.056" rpy="0 0 0" />
    <parent link="lift_carriage_link" />
    <child link="a_right_base_link" />
    <axis xyz="0 0 0" />
  </joint>
  <link name="a_right_link1">
    <inertial>
      <origin xyz="9.64709983311621E-05 -0.000526979727385357 0.0539265681374985" rpy="0 0 0" />
      <mass value="0.0833530095742827" />
      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
    </inertial>
    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
  </link>
  <joint name="a_right_joint1" type="revolute">
    <origin xyz="0 0 0.0365" rpy="0 0 0" />
    <parent link="a_right_base_link" />
    <child link="a_right_link1" />
    <axis xyz="0 0 1" />
    <limit lower="-0.3" upper="1.5" effort="27" velocity="50" />
  </joint>
  <link name="a_right_link2">
    <inertial>
      <origin xyz="-0.132246385887772 -0.00387496570683443 0.00306722076781929" rpy="0 0 0" />
      <mass value="0.705349739064212" />
      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
    </inertial>
    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
  </link>
  <joint name="a_right_joint2" type="revolute">
    <origin xyz="0.02 0.004675 0.0897" rpy="0 0 0" />
    <parent link="a_right_link1" />
    <child link="a_right_link2" />
    <axis xyz="0 -1 0" />
    <limit lower="-3.14" upper="0" effort="27" velocity="50" />
  </joint>
  <link name="a_right_link3">
    <inertial>
      <origin xyz="0.123498314020929 -0.00389750455678084 0.0542348768186509" rpy="0 0 0" />
      <mass value="0.52520909407384" />
      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
    </inertial>
    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
  </link>
  <joint name="a_right_joint3" type="revolute">
    <origin xyz="-0.264 0 0" rpy="0 0 0" />
    <parent link="a_right_link2" />
    <child link="a_right_link3" />
    <axis xyz="0 1 0" />
    <limit lower="-3.14" upper="0" effort="27" velocity="50" />
  </joint>
  <link name="a_right_link4">
    <inertial>
      <origin xyz="0.0635507417115015 -0.00290463621996007 0.0533154391743242" rpy="0 0 0" />
      <mass value="0.182914560739641" />
      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
    </inertial>
    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
  </link>
  <joint name="a_right_joint4" type="revolute">
    <origin xyz="0.2426 -0.0019048 0.054146" rpy="0 0 0" />
    <parent link="a_right_link3" />
    <child link="a_right_link4" />
    <axis xyz="0 1 0" />
    <limit lower="-1.4" upper="1.57" effort="7" velocity="200" />
  </joint>
  <link name="a_right_link5">
    <inertial>
      <origin xyz="-0.00208877175564695 0.000146333125480402 -0.0617707400113767" rpy="0 0 0" />
      <mass value="0.134196923597164" />
      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
    </inertial>
    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
  </link>
  <joint name="a_right_joint5" type="revolute">
    <origin xyz="0.078308 -0.0029167 0.062583" rpy="0 0 0" />
    <parent link="a_right_link4" />
    <child link="a_right_link5" />
    <axis xyz="0 0 -1" />
    <limit lower="-1.57" upper="1.57" effort="7" velocity="200" />
  </joint>
  <link name="a_right_link6">
    <inertial>
      <origin xyz="0.0655269830862821 6.98989603294398E-05 -0.000143922297662025" rpy="0 0 0" />
      <mass value="0.190049959858017" />
      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
    </inertial>
    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
  </link>
  <joint name="a_right_joint6" type="revolute">
    <origin xyz="0.00046248 0.0001465 -0.065083" rpy="0 0 0" />
    <parent link="a_right_link5" />
    <child link="a_right_link6" />
    <axis xyz="1 0 0" />
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

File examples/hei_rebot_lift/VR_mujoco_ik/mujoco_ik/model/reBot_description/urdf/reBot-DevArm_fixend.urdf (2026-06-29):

<?xml version="1.0" encoding="utf-8"?>
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
<robot name="reBot-DevArm_fixend">
  <link name="base_link">
    <inertial>
      <origin xyz="-7.849E-06 -1.1531E-06 0.029841" rpy="0 0 0" />
      <mass value="0.83660000" />
      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
    </inertial>
    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
  </link>
  <link name="link1">
    <inertial>
      <origin xyz="0.000113614552951627 -0.000616319527051323 0.0236476372671394" rpy="0 0 0" />
      <mass value="0.16130000" />
      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
    </inertial>
    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
  </link>
  <joint name="joint1" type="revolute">
    <origin xyz="-8.416E-05 0 0.08465" rpy="0 0 0" />
    <parent link="base_link" />
    <child link="link1" />
    <axis xyz="0 0 1" />
    <limit lower="-2.8" upper="2.8" effort="27" velocity="50" />
  </joint>
  <link name="link2">
    <inertial>
      <origin xyz="-0.13225622308888 -0.0030617036386309 -0.0308306967030205" rpy="0 0 0" />
      <mass value="1.32660000" />
      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
    </inertial>
    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
  </link>
  <joint name="joint2" type="revolute">
    <origin xyz="0.020084 0.031625 0.05555" rpy="-1.5708 0 0" />
    <parent link="link1" />
    <child link="link2" />
    <axis xyz="0 0 -1" />
    <limit lower="-3.14" upper="0" effort="27" velocity="50" />
  </joint>
  <link name="link3">
    <inertial>
      <origin xyz="0.121040035791843 -0.0536211076627949 -0.0310137854608077" rpy="0 0 0" />
      <mass value="0.83530000" />
      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
    </inertial>
    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
  </link>
  <joint name="joint3" type="revolute">
    <origin xyz="-0.264 0 0" rpy="0 0 0" />
    <parent link="link2" />
    <child link="link3" />
    <axis xyz="0 0 1" />
    <limit lower="-3.14" upper="0" effort="27" velocity="50" />
  </joint>
  <link name="link4">
    <inertial>
      <origin xyz="0.0608200956293136 -0.0511711906613122 -0.030299458623927" rpy="0 0 0" />
      <mass value="0.52000000" />
      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
    </inertial>
    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
  </link>
  <joint name="joint4" type="revolute">
    <origin xyz="0.2426 -0.054 -0.001625" rpy="0 0 0" />
    <parent link="link3" />
    <child link="link4" />
    <axis xyz="0 0 1" />
    <limit lower="-1.87" upper="1.57" effort="7" velocity="200" />
  </joint>
  <link name="link5">
    <inertial>
      <origin xyz="-0.00502802058982517 1.73866206692364E-06 0.0386233236326755" rpy="0 0 0" />
      <mass value="0.38300000" />
      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
    </inertial>
    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
  </link>
  <joint name="joint5" type="revolute">
    <origin xyz="0.078308 -0.0375 -0.03" rpy="-1.5708 0 0" />
    <parent link="link4" />
    <child link="link5" />
    <axis xyz="0 0 1" />
    <limit lower="-1.57" upper="1.57" effort="7" velocity="200" />
  </joint>
  <link name="link6">
    <inertial>
      <origin xyz="3.76418727127126E-06 -0.000100908819946677 0.0253308606425965" rpy="0 0 0" />
      <mass value="0.36630000" />
      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
    </inertial>
    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
  </link>
  <joint name="joint6" type="revolute">
    <origin xyz="0.028008 0 0.04" rpy="0 1.5708 0" />
    <parent link="link5" />
    <child link="link6" />
    <axis xyz="0 0 1" />
    <limit lower="-3.14" upper="3.14" effort="7" velocity="200" />
  </joint>
  <link name="end_link">
    <inertial>
      <origin xyz="-0.0737654295815033 -9.5080995865868E-06 7.04327840286845E-06" rpy="0 0 0" />
      <mass value="0.4500000" />
      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
    </inertial>
    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
  </link>
  <joint name="end_joint" type="fixed">
    <origin xyz="0 0 0.15539" rpy="0 -1.5708 3.1415" />
    <parent link="link6" />
    <child link="end_link" />
    <axis xyz="0 0 0" />
  </joint>
</robot>

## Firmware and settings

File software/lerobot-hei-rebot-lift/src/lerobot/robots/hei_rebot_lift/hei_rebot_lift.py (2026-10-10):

#!/usr/bin/env python

import importlib
import logging
import time
from contextlib import suppress
from functools import cached_property
from typing import Any

import numpy as np

from lerobot.cameras import make_cameras_from_configs
from lerobot.lerobot_types import RobotAction, RobotObservation
from lerobot.utils.decorators import check_if_already_connected, check_if_not_connected

from ..robot import Robot
from .config_hei_rebot_lift import HeiRebotLiftConfig

logger = logging.getLogger(__name__)

ARM_JOINTS = ("joint_1", "joint_2", "joint_3", "joint_4", "joint_5", "joint_6", "gripper")
ARM_JOINT_COUNT = 6
ARM_QPOS_COUNT = 7
TWO_PI = 2.0 * np.pi

# Motor order from the validated u2can scripts: [RF, RR, LR, LF].
O_TYPE_KINEMATICS = np.array(
    [
        [-1.0, -1.0, -1.0],
        [-1.0, 1.0, -1.0],
        [1.0, 1.0, -1.0],
        [1.0, -1.0, -1.0],
    ],
    dtype=float,
)


def _load_dm_can():
    try:
        return importlib.import_module("lerobot.motors.damiao_u2can")
    except ImportError as exc:
        raise ImportError(
            "HEI ReBot Lift requires the u2can Damiao backend in lerobot.motors.damiao_u2can."
        ) from exc


def _load_serial():
    try:
        return importlib.import_module("serial")
    except ImportError as exc:
        raise ImportError("pyserial is required for HEI ReBot Lift u2can/IO ports.") from exc


def _dm_motor_type(dm_can, motor_type: str):
    try:
        return getattr(dm_can.DM_Motor_Type, motor_type)
    except AttributeError as exc:
        valid = ", ".join(name for name in dir(dm_can.DM_Motor_Type) if name.startswith("DM"))
        raise ValueError(f"Unsupported Damiao motor type {motor_type!r}. Valid types: {valid}") from exc


def _crc16_modbus(data: bytes | bytearray) -> int:
    crc = 0xFFFF
    for value in data:
        crc ^= value
        for _ in range(8):
            if crc & 0x0001:
                crc = (crc >> 1) ^ 0xA001
            else:
                crc >>= 1
    return crc & 0xFFFF


class _LimitSwitchReader:
    def __init__(self, port: str, baudrate: int, upper_bit: int, lower_bit: int, timeout_s: float = 0.0):
        serial = _load_serial()
        self.serial = serial.Serial(port, baudrate, timeout=0.0)
        self.upper_mask = 1 << (upper_bit - 1)
        self.lower_mask = 1 << (lower_bit - 1)
        self.timeout_s = timeout_s
        self.buffer = bytearray()
        self.state = 0
        self.last_update_s = 0.0

    def close(self) -> None:
        self.serial.close()

    def poll(self) -> None:
        data = self.serial.read(256)
        if data:
            self.buffer.extend(data)
        self._parse_buffer()

    def _parse_buffer(self) -> None:
        while len(self.buffer) >= 7:
            start = self._find_frame_start()
            if start is None:
                self.buffer.clear()
                return
            if start > 0:
                del self.buffer[:start]
            if len(self.buffer) < 7:
                return

            frame = bytes(self.buffer[:7])
            del self.buffer[:7]
            if frame[0] != 0x01 or frame[1] != 0x04 or frame[2] != 0x02 or frame[3] != 0x00:
                continue
            frame_crc = frame[5] | (frame[6] << 8)
            if _crc16_modbus(frame[:5]) != frame_crc:
                continue
            if frame[4] not in (0x00, 0x01, 0x02, 0x03):
                continue
            self.state = frame[4]
            self.last_update_s = time.monotonic()

    def _find_frame_start(self) -> int | None:
        for index in range(len(self.buffer) - 3):
            if (
                self.buffer[index] == 0x01
                and self.buffer[index + 1] == 0x04
                and self.buffer[index + 2] == 0x02
                and self.buffer[index + 3] == 0x00
            ):
                return index
        return None

    @property
    def upper_active(self) -> bool:
        return bool(self.state & self.upper_mask)

    @property
    def lower_active(self) -> bool:
        return bool(self.state & self.lower_mask)

    @property
    def both_active(self) -> bool:
        return self.upper_active and self.lower_active

    @property
    def online(self) -> bool:
        if self.timeout_s <= 0.0:
            return self.last_update_s > 0.0
        return self.last_update_s > 0.0 and time.monotonic() - self.last_update_s <= self.timeout_s


class _MultiTurnPositionTracker:
    def __init__(self, wrap_rad: float):
        self.wrap_rad = float(wrap_rad)
        self.half_wrap_rad = self.wrap_rad * 0.5
        self.last_raw_rad: float | None = None
        self.turn_offset_rad = 0.0

    def reset(self, raw_rad: float = 0.0) -> None:
        self.last_raw_rad = float(raw_rad)
        self.turn_offset_rad = -float(raw_rad)

    def update(self, raw_rad: float) -> float:
        raw_rad = float(raw_rad)
        if self.last_raw_rad is None:
            self.reset(raw_rad)
        else:
            delta = raw_rad - self.last_raw_rad
            if delta > self.half_wrap_rad:
                self.turn_offset_rad -= self.wrap_rad
            elif delta < -self.half_wrap_rad:
                self.turn_offset_rad += self.wrap_rad
            self.last_raw_rad = raw_rad
        return raw_rad + self.turn_offset_rad


def _write_motor_param_with_fallback(motor_control: Any, motor: Any, variable: Any, values: list[float]) -> None:
    for value in values:
        motor.temp_param_dict.pop(variable, None)
        if motor_control.change_motor_param(motor, variable, float(value)):
            return
        time.sleep(0.02)
    logger.warning("Failed to write motor parameter %s with candidates %s", variable, values)


def _joint_param_array(value: Any, name: str) -> np.ndarray:
    """Return one value per arm joint while keeping scalar configs backward compatible."""
    if np.isscalar(value):
        return np.full(ARM_JOINT_COUNT, float(value), dtype=float)
    array = np.asarray(value, dtype=float)
    if array.shape != (ARM_JOINT_COUNT,):
        raise ValueError(f"{name} must be a scalar or {ARM_JOINT_COUNT} values, got shape {array.shape}")
    return array


def _unique_fallback_values(*values: float) -> list[float]:
    result = []
    for value in values:
        value = float(value)
        if value not in result:
            result.append(value)
    return result
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

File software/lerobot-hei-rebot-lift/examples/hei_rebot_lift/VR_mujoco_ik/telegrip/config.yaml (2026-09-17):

network:
  host_ip: 0.0.0.0
  https_port: 8443
  websocket_port: 8442
ssl:
  certfile: cert.pem
  keyfile: key.pem
vr:
  enabled: true
  zmq_publish_endpoint: tcp://*:5567
  zmq_topic: vr_data
  controller_axes:
    enabled: true
vr_images:
  enabled: false
  opacity: 0.9
  endpoint: tcp://192.168.31.127:6556
  color_order: rgb
  socket_type: pull
  topic: ''
  width: 640
  height: 480
  fps: 30
  jpeg_quality: 95
  cameras:
    - id: front
      enabled: true
      name: Front
      image_key: front
    - id: left_wrist
      enabled: true
      name: Left Wrist
      image_key: left_wrist
    - id: right_wrist
      enabled: true
      name: Right Wrist
      image_key: right_wrist

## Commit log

2026-06-29 Add HEI ReBot Lift robot support
    [base_link.STL, link1.STL, link3.STL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]
2026-07-04 Update hardware assets and BOM
    [DM_4340P_banjin_falan.STEP, Purchased_Parts.xls, part_danpan_dm_zhijia.STEP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]
2026-07-04 Add default-open gripper VR IK variant
2026-07-06 Improve HEI ReBot Lift VR camera streaming
2026-07-31 Update hardware package and motor docs
    [DM_4340P_banjin_falan.STEP, HEI_Metal_Body_Parts_List.xlsx, HEI_ReBot_Lift_BOM.xlsx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]
2026-08-01 Add GitHub-readable hardware BOM
2026-08-01 Update hardware BOM with XT30 cable item
    [HEI_ReBot_Lift_BOM.xlsx]
2026-09-15 Add complete robot VR simulation and safe real control
    [HEI_robot_urdf.csv, HEI_robot_urdf.urdf, a_right_base_link.STL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]
2026-09-15 Invert VR gripper control to default closed
2026-09-16 Add VR arm limit and IK safety guards
2026-09-16 Revert "Add VR arm limit and IK safety guards"
    This reverts commit be72f80ca99bf13a082ffb3dff9a33b27c5509f9.
2026-09-17 Improve VR workspace projection and robot model colors
    [HEI_robot_urdf.urdf]
2026-09-17 Document Meta Quest controller buttons and recentering
2026-09-17 Add arm mechanical zero posture reference to calibration guides
2026-09-18 Document camera ID configuration and fix chassis keyboard directions
2026-09-18 Document Jetson system icon recovery and prevention
2026-09-18 Reduce lift keyboard step to 2 mm and update guides
2026-09-22 Update hardware assembly, printed parts, BOM V1.1, and tutorial
    [HEI_ReBot_Lift_BOM.xlsx, part_dianchi_ke_1.STL, part_dianchi_ke_2.STL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]
2026-09-22 Reorganize chassis printed part files
    [part_dipan_3-2.STL, part_dipan_3-3.STL, part_dipan_3-4.STL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]
2026-09-23 add a stl
    [part_waike_6.STL]
2026-09-24 Optimize multi-camera discovery with MJPG
2026-09-24 Add interactive camera udev binding
2026-09-24 Clarify camera mapping configuration
2026-10-01 Smooth MuJoCo arm IK tracking
2026-10-08 Support CH341 serial device names
2026-10-09 Increase chassis yaw speed scale
2026-10-10 Fix VR buttons and update lift range
    [HEI_robot_urdf.urdf]
2026-10-26 Document Pi0.5 remote inference and add printed part
